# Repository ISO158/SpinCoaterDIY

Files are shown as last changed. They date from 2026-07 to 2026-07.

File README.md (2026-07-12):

# Spin Coater (DIY)

Este projeto consiste no desenvolvimento e validação de um **Spin Coater de baixo custo (DIY)** voltado para a instrumentação e preparação de amostras em biofísica de membranas. Utilizando peças impressas em 3D, componentes de drones e um microcontrolador ESP32, o equipamento foi projetado para produzir filmes lipídicos finos e homogêneos sobre lâminas de vidro com alta reprodutibilidade.

---

## 📺 Demonstração em Vídeo

Você pode conferir o funcionamento prático do Spin Coater através do vídeo abaixo:

Demonstração do Spin Coater (https://www.youtube.com/shorts/L5SzGOxu2F8)

> 🎥 *Clique na imagem acima para assistir ao funcionamento do Spin Coater no YouTube Shorts.*

---

## 🛠️ Especificações de Hardware e Eletrônica

O projeto integra hardware de modelagem própria e componentes robustos gerenciados pelo ESP32.

### 🔌 Diagrama Elétrico
Abaixo está o esquema de conexões da eletrônica, englobando a fonte chaveada, o conversor de tensão DC-DC, o microcontrolador e a telemetria do motor:
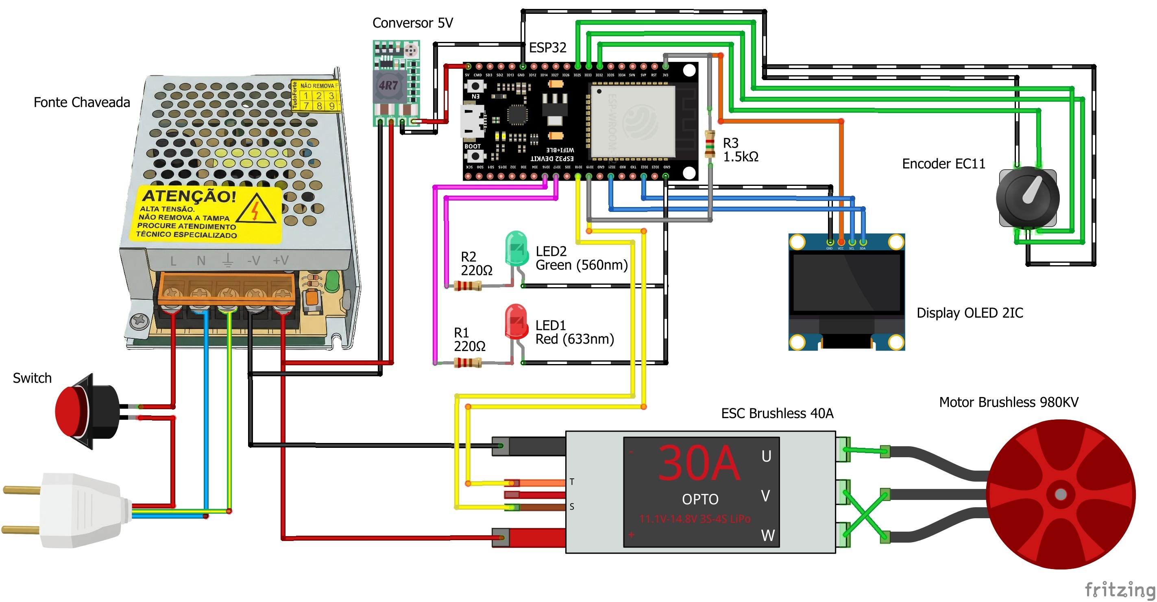
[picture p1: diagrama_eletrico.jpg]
Diagrama Elétrico


*   **Microcontrolador:** ESP32 DevKit v1
*   **Motorização:** Motor Brushless Outrunner 980KV (comum em drones) acoplado a um ESC Brushless de 40A com telemetria ativa.
*   **Interface Física:** Display OLED I2C (SSD1306 128x64) e um Encoder Rotativo EC11 com botão integrado para navegação nos menus.
*   **Sinalização:** LEDs indicadores (Verde/Vermelho) para status de operação segura.

### 📐 Estrutura Física e Modelagem 3D (OpenSCAD)
O gabinete externo e o arranjo dos componentes internos foram inteiramente modelados em OpenSCAD. A carcaça estrutural foi projetada com **5mm de espessura**, permitindo um preenchimento do tipo *Gyroid* (efeito sanduíche) para minimizar tensões térmicas e vibrações de alta rotação.
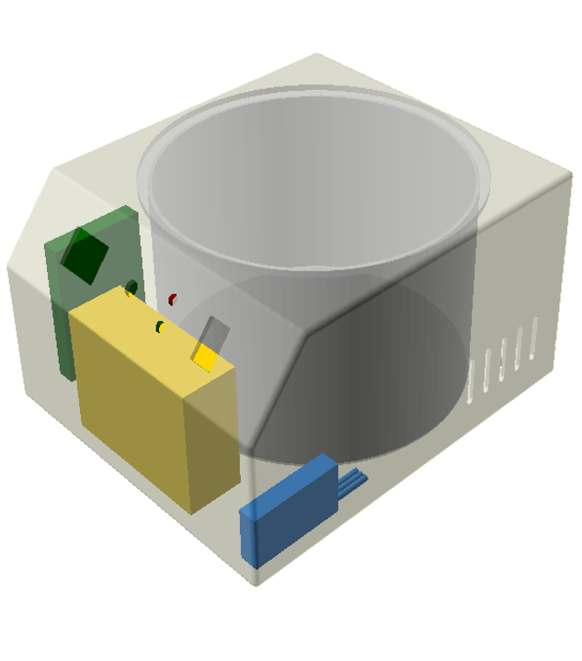
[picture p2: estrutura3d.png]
Estrutura 3D renderizada


A câmara de centrifugação utiliza uma **forma de alumínio de 16cm de diâmetro**, fixada à base por parafusos M6 e isolada por amortecimento de EVA para conter respingos e estabilizar mecanicamente o sistema. Os pés do gabinete possuem furação para parafusos M8.

Aqui está o equipamento montado e finalizado:
<p align="center">
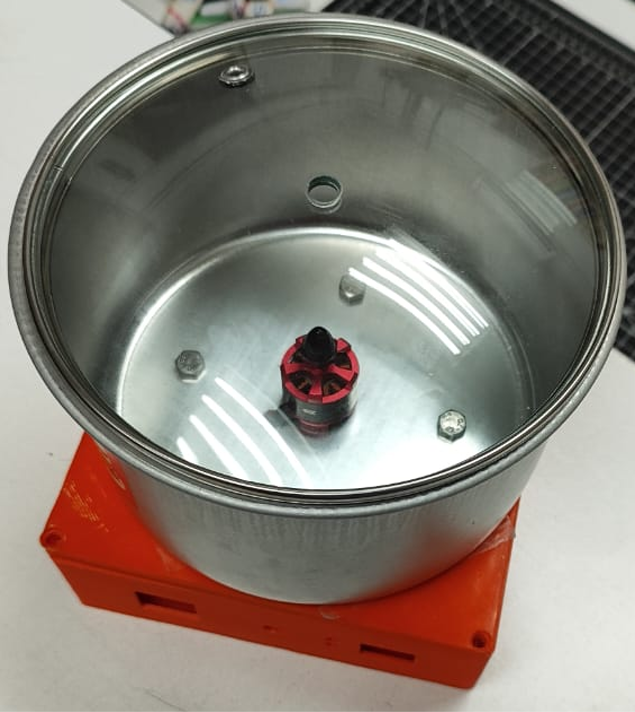
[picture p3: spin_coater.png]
Montagem Interna
  
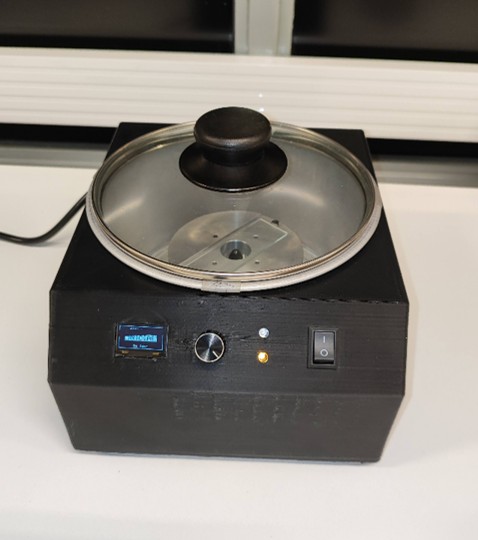
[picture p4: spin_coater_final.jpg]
Produto Finalizado
  
</p>

---

## 💻 Arquitetura do Firmware (ESP32)

O código desenvolvido em C++ implementa uma máquina de estados robusta (`TELA_HOME`, `TELA_CONFIG`, `MODO_DEPOSICAO`, `MODO_SPIN`, `MODO_FREIO`, etc.) e algoritmos críticos de automação industrial:

1.  **Vencimento de Inércia (*Kickstart*):** Ao iniciar, o motor recebe um pulso de PWM de $1150\,\mu\text{s}$ por $150\,\text{ms}$ para vencer o peso inicial do mandril de fixação (*chuck*).
2.  **Rampa de Aceleração Controlada:** Aceleração linear com duração fixa de $2000\,\text{ms}$ para evitar o descolamento abrupto da solução lipídica.
3.  **Compensador de Carga Ativo:** Em alta rotação (acima de $4650\text{ RPM}$), o firmware faz leituras contínuas da telemetria a cada $200\,\text{ms}$. Se a rotação real desviar mais de $100\text{ RPM}$ do alvo (`TOLERANCIA_CARGA`), o PWM é ajustado dinamicamente via software para compensar o arrasto aerodinâmico.
4.  **Frenagem Dinâmica Suave:** O motor desacelera em passos controlados de PWM para impedir danos ao eixo do motor ou deslocamento indesejado da amostra antes do corte total de inércia.

---

## 📊 Resultados e Validação

O sistema foi rigorosamente calibrado e testado para avaliar a estabilidade eletrônica, o comportamento mecânico e a qualidade biológica dos filmes obtidos.

### 📈 Calibração de Velocidade e Resíduos
A resposta de velocidade (RPM) em função do sinal PWM ($\mu\text{s}$) apresentou excelente comportamento linear em toda a faixa de operação do motor. A dispersão dos resíduos se mantém muito baixa, permitindo alta fidelidade na seleção da rotação.
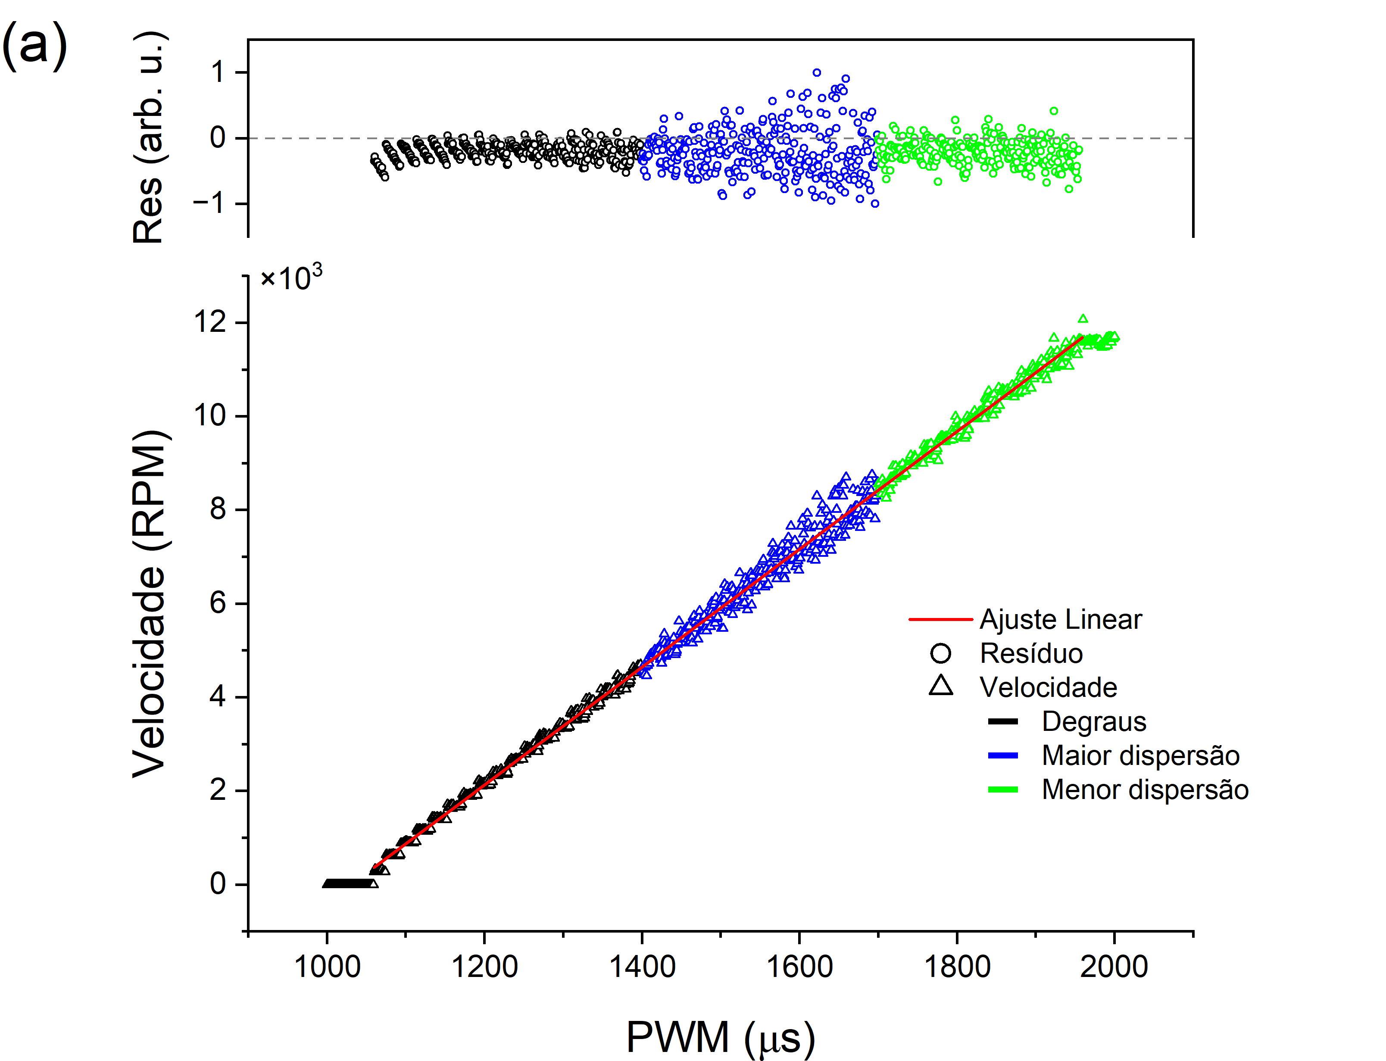
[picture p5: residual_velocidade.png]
Ajuste Linear de Velocidade


### 🌡️ Tensão e Temperatura
A telemetria monitorou a temperatura do ESC e a tensão da fonte durante os testes. A temperatura segue um ajuste quadrático esperado devido ao efeito Joule, estabilizando-se em níveis seguros abaixo de $44^\circ\text{C}$, enquanto a tensão da fonte chaveada permanece perfeitamente estável em torno de $12.6\text{ V}$.
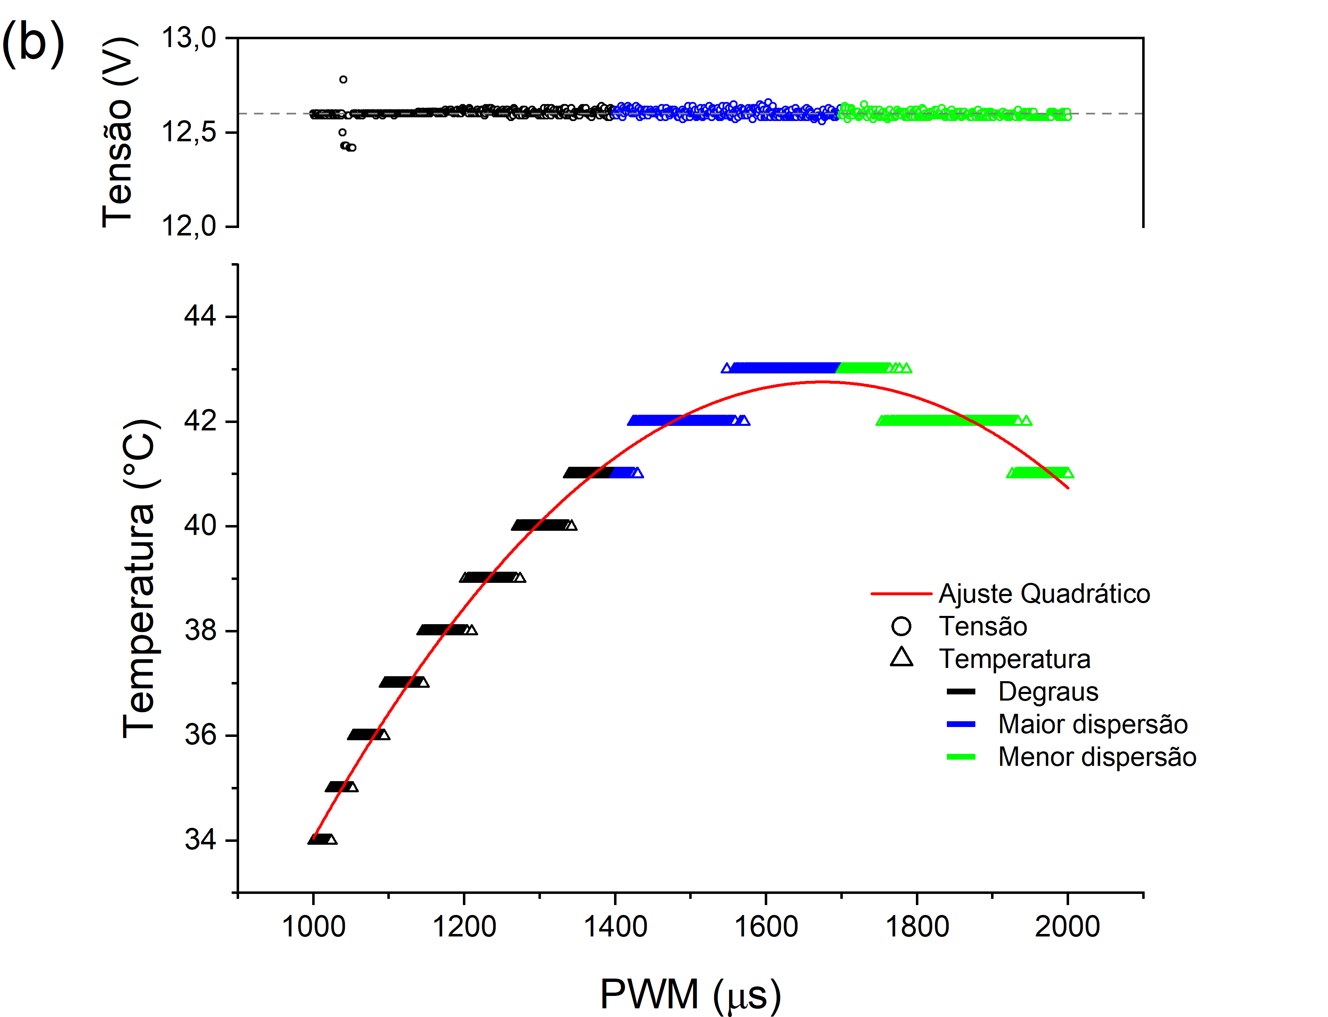
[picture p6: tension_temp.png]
Gráfico de Tensão e Temperatura


### 🔬 Homogeneidade das Amostras Lipídicas
O teste definitivo de bancada validou o propósito biológico do equipamento. Na imagem abaixo, é possível ver o contraste entre uma deposição manual (A) e o filme lipídico uniforme gerado pelo Spin Coater (B). Sob microscopia (C), a transição nítida evidencia a formação de um filme extremamente fino e homogêneo sobre a lâmina de vidro.
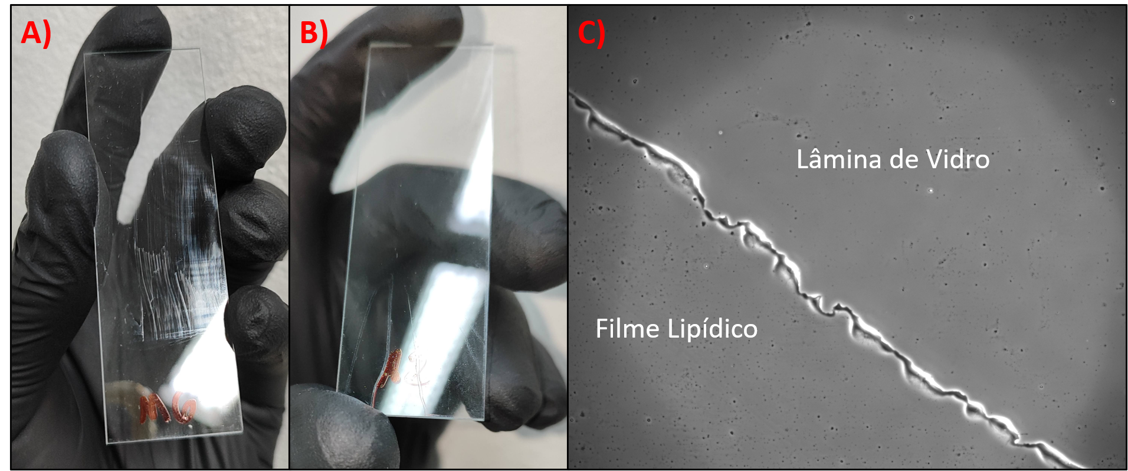
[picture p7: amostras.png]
Comparativo de Amostras


---

## 🛠️ Como Executar o Projeto

1.  **Modelagem 3D:** Os arquivos `.scad` podem ser modificados e exportados para `.STL` utilizando o [OpenSCAD](https://openscad.org/).
2.  **Firmware:** 
    *   Abra o código na Arduino IDE ou PlatformIO.
    *   Instale as bibliotecas necessárias: `Adafruit_GFX`, `Adafruit_SSD1306` e `ESP32Servo`.
    *   Compile e faça o upload para o ESP32 conectado às pinagens indicadas no cabeçalho do código.

---
*Desenvolvido por **Igor** como parte de soluções instrumentais aplicadas à pesquisa científica.*

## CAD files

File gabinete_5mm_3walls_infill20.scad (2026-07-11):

// ==========================================
// PROJETO SPIN COATER - VERSÃO FINAL (5mm ESTRUTURAL)
// ==========================================

// --- DIMENSÕES DO GABINETE (mm) ---
// Decisão Final: 5mm permite infill Gyroid funcional (efeito sanduíche)
// reduzindo a tensão térmica interna comparado a uma parede fina sólida.
espessura_base_topo = 5; 
espessura_laterais = 5;  

largura_total = 180;  
profundidade_total = 210; 
altura_total = 107;   

raio_arredondamento = 3; 

// --- GEOMETRIA DO TRAPÉZIO FRONTAL ---
altura_base_painel = 70;  
altura_topo_painel = 100; 
recuo_painel = 30; 

// --- POSIÇÃO DO BURACO DA FORMA ---
raio_forma = 80; // 16cm diâmetro
// Distância do fundo ajustada para parede de 5mm
y_centro_forma = profundidade_total - espessura_laterais - 5 - raio_forma;

// --- CÁLCULO DO ÂNGULO DO PAINEL ---
cateto_oposto = recuo_painel;
cateto_adjacente = altura_topo_painel - altura_base_painel;
angulo_painel = atan(cateto_oposto / cateto_adjacente); 

$fn = 100; 

module CorpoGabinete() {
    hull() {
        // --- PARTE TRASEIRA ---
        translate([raio_arredondamento, profundidade_total-raio_arredondamento, raio_arredondamento]) sphere(r=raio_arredondamento);
        translate([largura_total-raio_arredondamento, profundidade_total-raio_arredondamento, raio_arredondamento]) sphere(r=raio_arredondamento);
        translate([raio_arredondamento, profundidade_total-raio_arredondamento, altura_total-raio_arredondamento]) sphere(r=raio_arredondamento);
        translate([largura_total-raio_arredondamento, profundidade_total-raio_arredondamento, altura_total-raio_arredondamento]) sphere(r=raio_arredondamento);
        
        // --- PARTE FRONTAL ---
        translate([raio_arredondamento, raio_arredondamento, raio_arredondamento]) sphere(r=raio_arredondamento);
        translate([largura_total-raio_arredondamento, raio_arredondamento, raio_arredondamento]) sphere(r=raio_arredondamento);
        
        translate([raio_arredondamento, raio_arredondamento, altura_base_painel]) sphere(r=raio_arredondamento);
        translate([largura_total-raio_arredondamento, raio_arredondamento, altura_base_painel]) sphere(r=raio_arredondamento);
        
        translate([raio_arredondamento, recuo_painel + raio_arredondamento, altura_topo_painel]) sphere(r=raio_arredondamento);
        translate([largura_total-raio_arredondamento, recuo_painel + raio_arredondamento, altura_topo_painel]) sphere(r=raio_arredondamento);
        
        translate([raio_arredondamento, recuo_painel + raio_arredondamento, altura_total-raio_arredondamento]) sphere(r=raio_arredondamento);
        translate([largura_total-raio_arredondamento, recuo_painel + raio_arredondamento, altura_total-raio_arredondamento]) sphere(r=raio_arredondamento);
    }
}

module GabineteFinal() {
    difference() {
        // 1. Sólido Externo
        CorpoGabinete();
        
        // 2. Oco Interno (AGORA UNIFORME 8mm)
        altura_interna = altura_total - (2 * espessura_base_topo);

        difference() {
            hull() {
                // Fundo Traseiro
                translate([espessura_laterais, profundidade_total-espessura_laterais, espessura_base_topo]) 
                cylinder(r=1, h=altura_interna);
                translate([largura_total-espessura_laterais, profundidade_total-espessura_laterais, espessura_base_topo]) 
                cylinder(r=1, h=altura_interna);
                
                // Frente Baixo
                translate([espessura_laterais, espessura_laterais, espessura_base_topo]) 
                cylinder(r=1, h=altura_base_painel - espessura_base_topo);
                translate([largura_total-espessura_laterais, espessura_laterais, espessura_base_topo]) 
                cylinder(r=1, h=altura_base_painel - espessura_base_topo);
                
                // Frente Angulo
                translate([espessura_laterais, recuo_painel+3, altura_topo_painel - espessura_base_topo]) cylinder(r=1, h=1);
                translate([largura_total-espessura_laterais, recuo_painel+3, altura_topo_painel - espessura_base_topo]) cylinder(r=1, h=1);
                    
                // Frente Topo
                translate([espessura_laterais, recuo_painel+3, altura_total - espessura_base_topo]) cylinder(r=1, h=1);
                translate([largura_total-espessura_laterais, recuo_painel+3, altura_total - espessura_base_topo]) cylinder(r=1, h=1);
            }
             translate([0,0,-5]) cube([largura_total, profundidade_total, 1]); 
        }
        
        // --- FURO DA FORMA ---
        translate([largura_total/2, y_centro_forma, altura_total - 20]) cylinder(h = 30, r = raio_forma+4);
        // Fresta de 2mm no topo (rebaixo visual)
        translate([largura_total/2, y_centro_forma, altura_total-2]) cylinder(r=raio_forma+4, h=3);

        // --- COMPONENTES FRONTAIS ---
        z_centro_face = (altura_base_painel + altura_topo_painel) / 2;
        y_centro_face = recuo_painel / 2; 
        
        translate([0, y_centro_face + 5, z_centro_face]) 
        rotate([angulo_painel, 0, 0]) 
        {
            // Display
            translate([2*largura_total/5 -(25), 0, 0]) cube([26, 17, 50], center=true);
            // Rebaixo visual do display (mantido do original)
            rotate([3.5, 0, 0]) translate([2*largura_total/5 -(25), 0, 0]) cube([15, 26, 8], center=true);
            
            // Encoder
            translate([largura_total/2 -(7.2), 0, 0]) cylinder(h=50, r=3.6, center=true);
            // Rebaixo visual do Encoder (mantido do original)
            rotate([3.5, 0, 0]) translate([largura_total/2 -(7.2), 0, 0]) cube([15, 15, 8], center=true); 
            
            // LEDs
            translate([3*largura_total/5 -(0), +6,0]) cylinder(h=50, r=2.6, center=true); 
            translate([3*largura_total/5 -(0),-6,0]) cylinder(h=50, r=2.6, center=true); 
            
            // Interruptor
            translate([4*largura_total/5 -(6.5), 0,0]) cube([13, 19, 50], center=true);
            // Rebaixo visual do Interruptor (mantido do original)
            rotate([3.5, 0, 0]) translate([4*largura_total/5 -(6.5), 0, 0]) cube([16, 22, 8], center=true);
        }
        
        // --- SAÍDA CABO ---
        translate([largura_total-largura_total/4, profundidade_total+10, 15]) 
        rotate([90,0,0])
        hull() { 
            cylinder(h=20, r=4);
            translate([0, 0, 0]) cylinder(h=20, r=4);
        }
        
        // --- VENTILAÇÃO ---
        for(lado = [0, largura_total]) {
            translate([lado, 2*profundidade_total/3, 40]) 
            rotate([0, 90, 0])
            for(i=[0:4]) {
                translate([0, i*12, -10])
                hull() {
                    cylinder(r=2, h=20);
                    translate([20, 0, 0]) cylinder(r=2, h=20);
                }
            }
        }
        
        // --- PÉS M8 ---
        posicoes_pes = [
            [20, 20],
            [largura_total-20, 20],
            [20, profundidade_total-20],
            [largura_total-20, profundidade_total-20]
        ];
    
        for(pos = posicoes_pes) {
            translate([pos[0], pos[1], -10]) 
            cylinder(r=4, h=30); 
        }
        
        // --- FUROS FORMA M6 NA BASE ---
        distancia_furos_forma = 100; 
        diametro_furo_m6 = 6.2; 
        translate([largura_total/2, y_centro_forma, 0]) {
            translate([distancia_furos_forma / 2, 0, 0]) cylinder(h=20, d=diametro_furo_m6, center=true);
            translate([distancia_furos_forma / 2, 0, 0]) cylinder(h=5, d=diametro_furo_m6+5, center=true);
            
            translate([-distancia_furos_forma / 2, 0, 0]) cylinder(h=20, d=diametro_furo_m6, center=true);
            translate([-distancia_furos_forma / 2, 0, 0]) cylinder(h=5, d=diametro_furo_m6+5, center=true);
            
            translate([0, distancia_furos_forma / 2, 0]) cylinder(h=20, d=diametro_furo_m6, center=true);
            translate([0, distancia_furos_forma / 2, 0]) cylinder(h=5, d=diametro_furo_m6+5, center=true);
            
            translate([0, -distancia_furos_forma / 2, 0]) cylinder(h=20, d=diametro_furo_m6, center=true);
            translate([0, -distancia_furos_forma / 2, 0]) cylinder(h=5, d=diametro_furo_m6+5, center=true);
        }
        
    }
}

// ==========================================
// --- MÓDULOS DE VISUALIZAÇÃO ---
// ==========================================

module FormaAluminio() {
    color("Silver", 0.8) {
        difference() {
            cylinder(r=raio_forma, h=97); 
            translate([0,0,2]) cylinder(r=raio_forma-2, h=95); 
        }
        translate([0,0,97]) difference() {
            cylinder(r=raio_forma+5, h=3);
        }
    }
}

module EVA_Amortecimento() {
    color("Black", 0.2) {
        cylinder(r=raio_forma-1, h=2); 
    }
}

module FonteChaveada() {
    color("Gold") cube([85, 30, 60]); 
}

module ESP32() {
    color("DarkGreen") cube([50, 10, 70]); 
}
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

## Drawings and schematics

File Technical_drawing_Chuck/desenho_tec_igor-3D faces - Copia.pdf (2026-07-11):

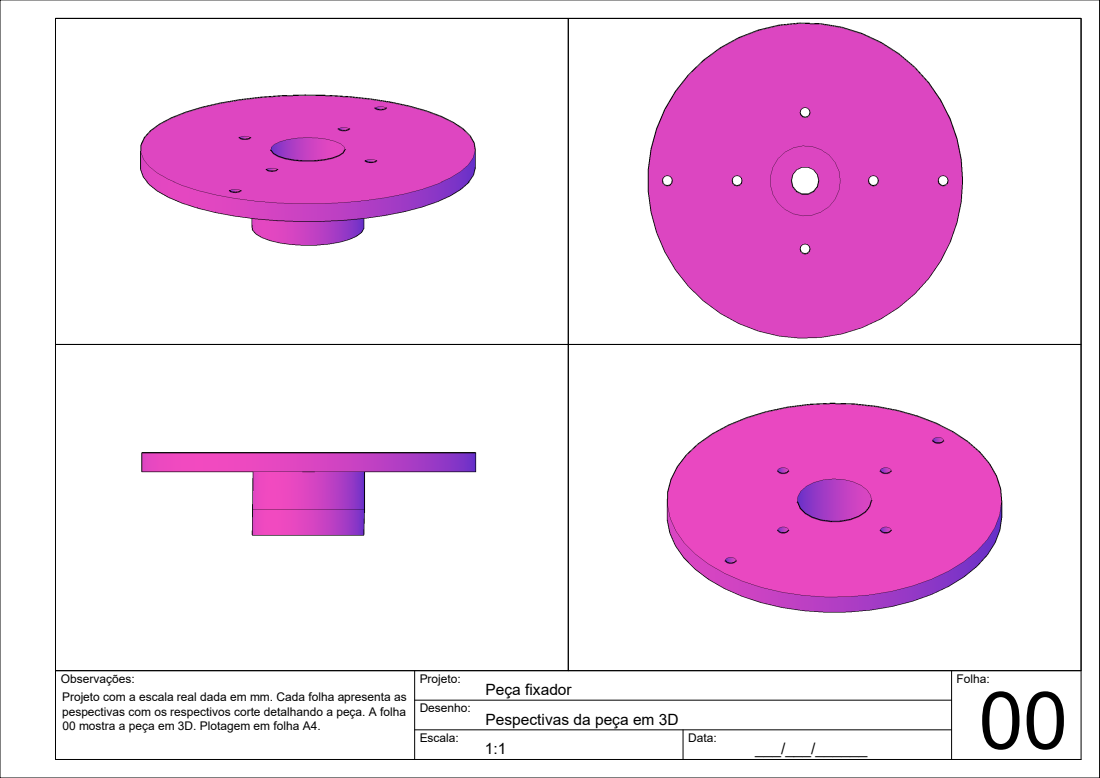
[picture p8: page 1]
Observações:; Peça fixador Projeto com a escala real dada em mm. Cada folha apresenta as

00 Pespectivas da peça em 3D

pespectivas com os respectivos corte detalhando a peça. A folha
00 mostra a peça em 3D. Plotagem em folha A4.

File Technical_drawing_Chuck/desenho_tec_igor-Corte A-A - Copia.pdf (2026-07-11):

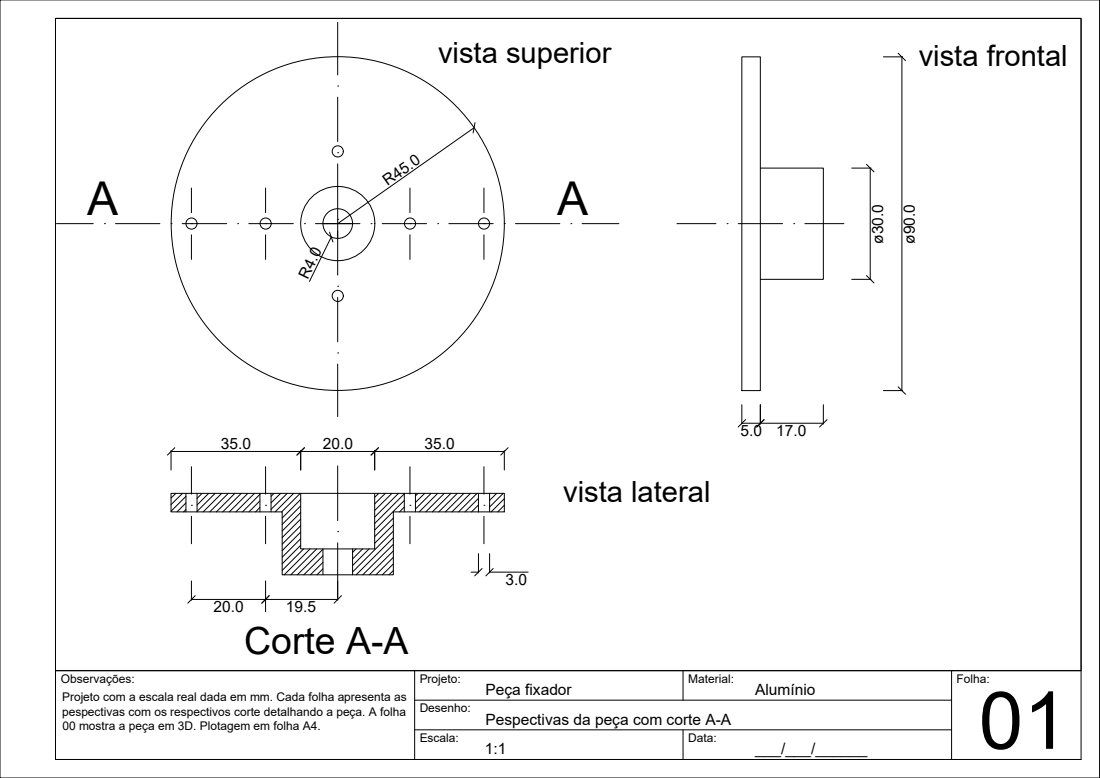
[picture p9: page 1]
vista superior; vista frontal; Corte A-A; vista lateral; Observações:; Peça fixador Projeto com a escala real dada em mm. Cada folha apresenta as

01 Pespectivas da peça com corte A-A

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

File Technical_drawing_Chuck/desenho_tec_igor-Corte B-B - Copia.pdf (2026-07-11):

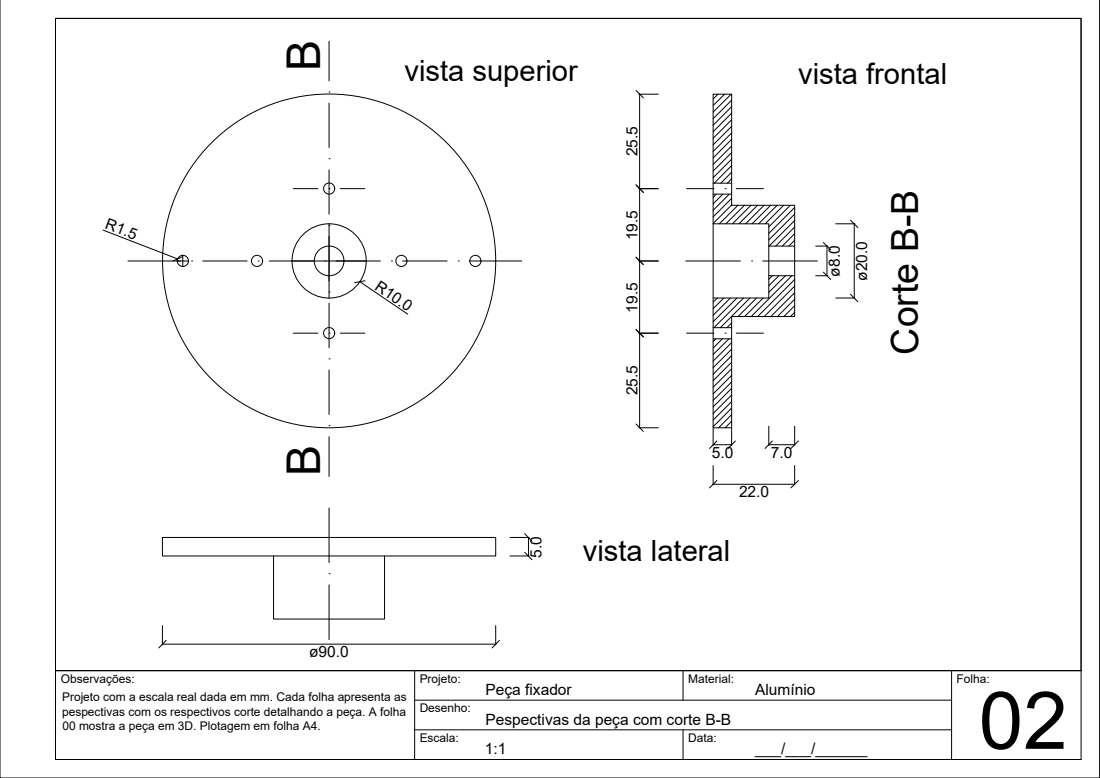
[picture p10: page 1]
vista superior; B Corte B-B; vista frontal; vista lateral; Observações:; Peça fixador Projeto com a escala real dada em mm. Cada folha apresenta as

02 Pespectivas da peça com corte B-B

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

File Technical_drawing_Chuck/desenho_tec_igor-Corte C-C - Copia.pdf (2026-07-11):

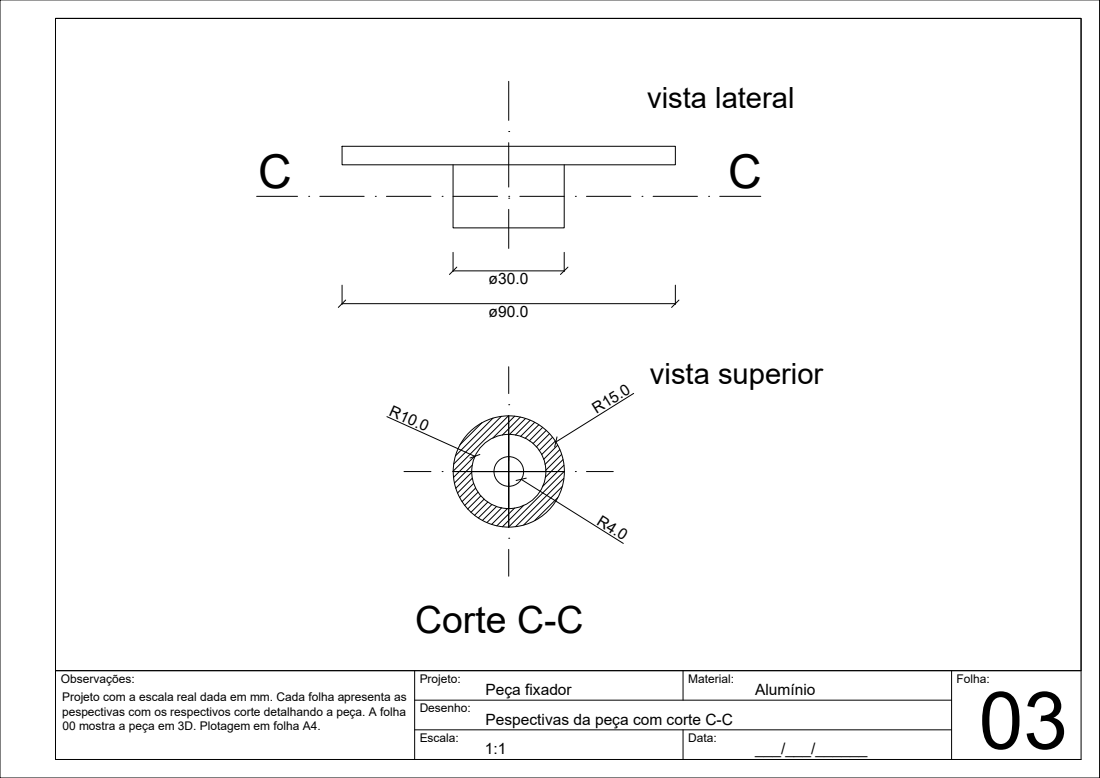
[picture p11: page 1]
vista lateral; vista superior; Corte C-C; Observações:; Peça fixador Projeto com a escala real dada em mm. Cada folha apresenta as

03 Pespectivas da peça com corte C-C

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

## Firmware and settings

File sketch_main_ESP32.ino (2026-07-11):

#include <Wire.h>
#include <Adafruit_GFX.h>
#include <Adafruit_SSD1306.h>
#include <ESP32Servo.h>

// ==========================================
// --- DEFINIÇÕES DE HARDWARE ---
// ==========================================

// --- PINAGEM DO MOTOR ---
const int escPin = 18;
const int pinTelemetria = 19;
const int PARES_DE_POLOS = 7;

// --- PINAGEM DOS LEDS ---
#define PIN_LED_VERMELHO 16 
#define PIN_LED_VERDE    17 

// --- PINAGEM DO ENCODER ---
#define ENC_CLK 25  
#define ENC_DT  33  
#define ENC_SW  32  

// ==========================================
// --- CONFIGURAÇÕES GERAIS ---
// ==========================================
#define INTERVALO_DISPLAY 500  
#define NUM_AMOSTRAS 50        
#define PWM_MIN 1055           
#define PWM_MAX 2000

#define PASSO_FREIO 4          
#define TEMPO_FREIO 20         

// ZONA DE CORTE (Hard Cut para não travar no fim)
#define PWM_CORTE_INERCIA 1130 

// Rampa de Aceleração (Tempo total em ms)
#define DURACAO_RAMPA 2000 

// --- PLATÔS SEGUROS (BAIXA ROTAÇÃO) ---
const int degrausSeguros[] = {
  570, 880, 1150, 1400, 1650, 1900, 2150, 2400, 2650, 
  2900, 3150, 3400, 3650, 3900, 4150, 4400, 4650 
};
const int numDegraus = sizeof(degrausSeguros) / sizeof(degrausSeguros[0]);

// A partir daqui, ativamos a CORREÇÃO DE CARGA
const int LIMITE_LINEAR = 4650; 

// ==========================================
// --- VARIÁVEIS GLOBAIS ---
// ==========================================
Servo esc;
Adafruit_SSD1306 display(128, 64, &Wire, -1);

int cfgDepositRPM = 570; 
int cfgMainRPM = 2150;    
int cfgTime = 30;         

long rpmMedio = 0;        
float voltagem = 0.0;     
float temperatura = 0.0;      

long amostrasRPM[NUM_AMOSTRAS]; 
int indiceAmostra = 0;
long somaAmostras = 0;

// Controle Motor
float pwmAtualFloat = 1000.0; 
int pwmAlvo = 1000;       
int pwmInicialRampa = 1000;
unsigned long inicioRampa = 0;
bool rampaAtiva = false;

// Compensador de Carga
unsigned long ultimoAjusteCarga = 0;
#define INTERVALO_COMPENSACAO 200 // Verifica a cada 200ms
#define TOLERANCIA_CARGA 100      // Só corrige se cair mais que 100 RPM

unsigned long tempoInicioSpin = 0;
unsigned long ultimaAtualizacaoDisplay = 0; 
unsigned long ultimoPassoFreio = 0; 

enum Estado { TELA_HOME, TELA_CONFIG, TELA_PRE_RUN, MODO_DEPOSICAO, MODO_SPIN, MODO_FREIO, TELA_FIM };
Estado estadoAtual = TELA_HOME;

int cursorLinha = 0;
int cursorPreRun = 0; 
bool botaoPressionado = false;
unsigned long ultimoClick = 0;

volatile int encoderCount = 0;
int lastEncoderCount = 0;

int indexDeposit = 0; 
int indexMain = 6;    

// ==========================================
// --- FUNÇÕES AUXILIARES ---
// ==========================================

// --- ENCODER E CRC ---
void IRAM_ATTR isrEncoder() {
  static unsigned long lastInterruptTime = 0;
  unsigned long interruptTime = millis();
  if (interruptTime - lastInterruptTime > 5) { 
    if (digitalRead(ENC_CLK) == digitalRead(ENC_DT)) {
      encoderCount--;
    } else {
      encoderCount++;
    }
    lastInterruptTime = interruptTime;
  }
}

uint8_t updateCrc8(uint8_t crc, uint8_t crc_seed) {
  uint8_t crc_u = crc ^ crc_seed;
  for (int i = 0; i < 8; i++) crc_u = (crc_u & 0x80) ? 0x7 ^ (crc_u << 1) : (crc_u << 1);
  return crc_u;
}

// --- CALIBRAÇÃO LINEAR ---
int rpmToPwmEstimado(int rpm) {
  if (rpm < 100) return 1000;
  float pwm = (0.0795 * rpm) + 1031;
  if (pwm < PWM_MIN) pwm = PWM_MIN;
  if (pwm > PWM_MAX) pwm = PWM_MAX;
  return (int)pwm;
}

// --- VISUAL ---
void desenharOpcaoInvertida(String texto, int y, bool selecionado) {
  int x = (128 - (texto.length() * 6)) / 2;
  if (selecionado) {
    display.fillRect(x - 2, y - 1, (texto.length() * 6) + 4, 10, WHITE);
    display.setTextColor(BLACK, WHITE);
  } else {
    display.setTextColor(WHITE);
  }
  display.setCursor(x, y); display.print(texto); display.setTextColor(WHITE);
}

void desenharBotaoGrande(String texto, int y, bool selecionado) {
  int larguraPx = texto.length() * 12;
  int x = (128 - larguraPx) / 2;
  display.setTextSize(2);
  if (selecionado) {
    display.fillRect(x - 4, y - 2, larguraPx + 8, 18, WHITE);
    display.setTextColor(BLACK, WHITE);
  } else {
    display.setTextColor(WHITE);
  }
  display.setCursor(x, y); display.print(texto); display.setTextColor(WHITE); display.setTextSize(1);
}

void desenharLinhaConfig(String label, String valor, String unidade, int y, bool selecionado) {
  if (selecionado) {
    display.fillRect(2, y - 1, 124, 10, WHITE);
    display.setTextColor(BLACK, WHITE);
  } else {
    display.setTextColor(WHITE);
  }
  display.setCursor(4, y); display.print(label);
  display.setCursor(65, y); display.print(valor); display.print(" "); display.print(unidade);
  display.setTextColor(WHITE);
}

void desenharDashboard(long rpmReal, int tempoTotal, int tempoRestante, int modo) {
  display.setTextSize(1);
  display.setCursor(4, 4); display.print(voltagem, 1); display.print(" V");
  display.setCursor(90, 4); display.print(temperatura, 1); display.print(" C");

  display.setTextSize(2);
  String sRpm = String(rpmReal);
  int xRpm = (128 - (sRpm.length() * 12)) / 2;
  xRpm -= 10; 
  display.setCursor(xRpm, 22); display.print(sRpm);
  display.setTextSize(1);
  display.setCursor(xRpm + (sRpm.length() * 12) + 2, 29); display.print("RPM");

  if (modo == 1 && tempoTotal > 0) { 
     display.drawRect(14, 45, 100, 6, WHITE);
     int tempoCorrido = tempoTotal - tempoRestante;
     int larguraBarra = map(tempoCorrido, 0, tempoTotal, 0, 96);
     if (larguraBarra > 96) larguraBarra = 96;
     display.fillRect(16, 47, larguraBarra, 2, WHITE);
     String sTempo = String(tempoRestante) + " s";
     int xTempo = (128 - (sTempo.length()*6))/2;
     display.setCursor(xTempo, 54); display.print(sTempo);
  }
  else if (modo == 2) { 
      display.setTextSize(1);
      desenharOpcaoInvertida("PARANDO...", 48, true);
  }
}

// ==========================================
// --- SETUP ---
// ==========================================
void setup() {
  Serial.begin(115200);

  // 1. INICIALIZAÇÃO IMEDIATA DO MOTOR (Evita bipes de erro)
  esc.setPeriodHertz(50);
  esc.attach(escPin, 1000, 2000);
  esc.writeMicroseconds(1000); // Crava o pino em 1000us na largada
  
  // O resto da placa continua inicializando enquanto o ESC lê o sinal zero
  pinMode(PIN_LED_VERMELHO, OUTPUT);
  pinMode(PIN_LED_VERDE, OUTPUT);
  
  digitalWrite(PIN_LED_VERMELHO, HIGH); delay(200); digitalWrite(PIN_LED_VERMELHO, LOW);
  digitalWrite(PIN_LED_VERDE, HIGH); delay(200); digitalWrite(PIN_LED_VERDE, LOW);

  for(int i=0; i<NUM_AMOSTRAS; i++) amostrasRPM[i] = 0;

  pinMode(ENC_CLK, INPUT_PULLUP);
  pinMode(ENC_DT, INPUT_PULLUP);
  pinMode(ENC_SW, INPUT_PULLUP);
  attachInterrupt(digitalPinToInterrupt(ENC_CLK), isrEncoder, RISING);

  // 2. INICIALIZA O DISPLAY
  if(!display.begin(SSD1306_SWITCHCAPVCC, 0x3C)) { for(;;); }
  display.setTextColor(WHITE);
  
  display.clearDisplay();
  display.setTextSize(1);
  display.setCursor(10,30); display.println("Booting System...");
  display.display();
  
  // 3. DELAY DE ARME DO ESC (A tela fica estática por 2s enquanto o motor bipa)
  delay(2000); 

  // 4. INICIALIZA A TELEMETRIA
  Serial2.begin(115200, SERIAL_8N1, pinTelemetria, -1);
}

void gerenciarLeds() {
  if (estadoAtual == MODO_DEPOSICAO || estadoAtual == MODO_SPIN || estadoAtual == MODO_FREIO) {
    digitalWrite(PIN_LED_VERMELHO, HIGH); 
    digitalWrite(PIN_LED_VERDE, LOW);
  } else {
    digitalWrite(PIN_LED_VERMELHO, LOW);
    digitalWrite(PIN_LED_VERDE, HIGH);    
  }
}

// ==========================================
// --- LÓGICA DE CONTROLE (RAMPA E CARGA) ---
// ==========================================
void iniciarNovaRampa(int novoAlvo) {
  pwmAlvo = novoAlvo;

  // --- KICKSTART PARA VENCER A INÉRCIA DO CHUCK ---
  // Se o motor estava desligado e mandamos ligar, dá um tranco de 150ms
  if (pwmAtualFloat < 1050 && novoAlvo > 1000) {
    esc.writeMicroseconds(1150); // PWM mais forte para o motor dar um "pulo"
    delay(150);                  // Tempo suficiente só para vencer a inércia
  }
  // ------------------------------------------------------

  // Jump Start para baixas velocidades (ignora rampa)
  if (pwmAlvo <= PWM_CORTE_INERCIA) {
    pwmAtualFloat = pwmAlvo;
    rampaAtiva = false; 
    esc.writeMicroseconds(pwmAlvo);
    return;
  }

  pwmInicialRampa = (int)pwmAtualFloat; 
  if (pwmInicialRampa < 1000) pwmInicialRampa = 1000;
  inicioRampa = millis();
  rampaAtiva = true;
}

void atualizarRampa() {
  if (!rampaAtiva) return;

  unsigned long tempoDecorrido = millis() - inicioRampa;

  if (tempoDecorrido >= DURACAO_RAMPA) {
    pwmAtualFloat = pwmAlvo;
    rampaAtiva = false;
  } 
  else {
    float progresso = (float)tempoDecorrido / (float)DURACAO_RAMPA;
    pwmAtualFloat = pwmInicialRampa + ((pwmAlvo - pwmInicialRampa) * progresso);
  }
  esc.writeMicroseconds((int)pwmAtualFloat);
}

// --- COMPENSADOR DE CARGA (Só p/ Alta Rotação) ---
void compensarCarga() {
  if (!rampaAtiva && pwmAlvo > rpmToPwmEstimado(LIMITE_LINEAR)) {
    if (millis() - ultimoAjusteCarga > INTERVALO_COMPENSACAO) {
      
      long erro = cfgMainRPM - rpmMedio;

      if (erro > TOLERANCIA_CARGA) {
         pwmAtualFloat += 1.0; 
         if (pwmAtualFloat > PWM_MAX) pwmAtualFloat = PWM_MAX;
         esc.writeMicroseconds((int)pwmAtualFloat);
      }
      else if (erro < -TOLERANCIA_CARGA) {
         pwmAtualFloat -= 1.0;
         if (pwmAtualFloat < PWM_MIN) pwmAtualFloat = PWM_MIN;
         esc.writeMicroseconds((int)pwmAtualFloat);
      }
      ultimoAjusteCarga = millis();
    }
  }
}

// ==========================================
// --- LOOP PRINCIPAL ---
// ==========================================
void loop() {
  processarTelemetria();
  gerenciarLeds();

  if (digitalRead(ENC_SW) == LOW) {
    if (millis() - ultimoClick > 300) {
      botaoPressionado = true;
      ultimoClick = millis();
    }
  }

  switch (estadoAtual) {
    case TELA_HOME:      loopHome();      break;
    case TELA_CONFIG:    loopConfig();    break;
    case TELA_PRE_RUN:   loopPreRun();    break;
    case MODO_DEPOSICAO: loopDeposicao(); break;
    case MODO_SPIN:      loopSpin();      break;
    case MODO_FREIO:     loopFreio();     break;
    case TELA_FIM:       loopFim();       break;
  }
}

void processarTelemetria() {
  while (Serial2.available() >= 10) {
    uint8_t buf[10];
    if (Serial2.peek() > 150) { Serial2.read(); continue; }
    Serial2.readBytes(buf, 10);
    uint8_t crc = 0;
    for (int i = 0; i < 9; i++) crc = updateCrc8(crc, buf[i]);
    if (crc == buf[9]) {
      uint16_t rpmWord = (buf[7] << 8) | buf[8];
      long leituraInstantanea = (long(rpmWord) * 100) / PARES_DE_POLOS;
      somaAmostras -= amostrasRPM[indiceAmostra]; 
      amostrasRPM[indiceAmostra] = leituraInstantanea; 
      somaAmostras += leituraInstantanea; 
      indiceAmostra++;
      if (indiceAmostra >= NUM_AMOSTRAS) indiceAmostra = 0; 
      rpmMedio = somaAmostras / NUM_AMOSTRAS;
      temperatura = buf[0];
      uint16_t voltageWord = (buf[1] << 8) | buf[2];
      voltagem = (float)voltageWord / 100.0;
    }
  }
}

bool horaDeAtualizarTela() {
  if (millis() - ultimaAtualizacaoDisplay > INTERVALO_DISPLAY) {
    ultimaAtualizacaoDisplay = millis();
    return true;
  }
  return false;
}

// ==========================================
// --- MÁQUINAS DE ESTADO ---
// ==========================================

void loopHome() {
  esc.writeMicroseconds(1000);
  pwmAtualFloat = 1000;
  rampaAtiva = false;
  if (botaoPressionado) {
    botaoPressionado = false;
    cursorLinha = 0; 
    cursorPreRun = 0;
    estadoAtual = TELA_CONFIG;
    display.clearDisplay(); 
    return;
  }
  if (horaDeAtualizarTela()) {
      display.clearDisplay();
      display.drawRect(0, 0, 128, 64, WHITE);
      display.setTextSize(1);
      display.setCursor(31,6); display.println("SPIN COATER");
      desenharBotaoGrande("INICIAR", 25, true); 
      display.setTextSize(1);
      display.setCursor(43, 52); display.println("by Igor");
      display.display();
  }
}

void loopConfig() {
  bool mudouAlgo = false;
  if (encoderCount != lastEncoderCount) {
    int delta = encoderCount - lastEncoderCount;
    mudouAlgo = true;
    
    if (cursorLinha == 0) { 
       if (cfgDepositRPM < LIMITE_LINEAR) {
          if (delta > 0) indexDeposit++; else indexDeposit--;
          if (indexDeposit < 0) indexDeposit = 0;
          if (indexDeposit >= numDegraus) indexDeposit = numDegraus - 1;
          cfgDepositRPM = degrausSeguros[indexDeposit];
       } else {
          cfgDepositRPM += delta * 100;
          if (cfgDepositRPM < LIMITE_LINEAR) {
             indexDeposit = numDegraus - 2; 
             cfgDepositRPM = degrausSeguros[indexDeposit];
          }
       }
       if (cfgDepositRPM > cfgMainRPM) cfgMainRPM = cfgDepositRPM;
    }
    else if (cursorLinha == 1) { 
       if (cfgMainRPM < LIMITE_LINEAR) {
          if (delta > 0) indexMain++; else indexMain--;
          if (indexMain < 0) indexMain = 0;
          if (indexMain >= numDegraus) indexMain = numDegraus - 1;
          cfgMainRPM = degrausSeguros[indexMain];
       } else {
          cfgMainRPM += delta * 100;
          if (cfgMainRPM < LIMITE_LINEAR) {
             indexMain = numDegraus - 2;
             cfgMainRPM = degrausSeguros[indexMain];
          }
       }
       if (cfgMainRPM < cfgDepositRPM) cfgMainRPM = cfgDepositRPM;
       if (cfgMainRPM > 12000) cfgMainRPM = 12000;
    }
    else if (cursorLinha == 2) { 
       cfgTime += delta;
       if (cfgTime < 1) cfgTime = 1;
       if (cfgTime > 600) cfgTime = 600;
    }
    lastEncoderCount = encoderCount;
  }

  if (botaoPressionado) {
    botaoPressionado = false;
    mudouAlgo = true;
    cursorLinha++;
    if (cursorLinha > 2) { 
       cursorLinha = 0;
       estadoAtual = TELA_PRE_RUN;
       display.clearDisplay(); 
       return;
    }
  }

  if (mudouAlgo || horaDeAtualizarTela()) {
      display.clearDisplay();
      display.drawRect(0, 0, 128, 64, WHITE);
      desenharLinhaConfig("Deposit", String(cfgDepositRPM), "RPM", 10, (cursorLinha==0));
      desenharLinhaConfig("Speed",   String(cfgMainRPM),    "RPM", 26, (cursorLinha==1));
      desenharLinhaConfig("Time",    String(cfgTime),       "s",   42, (cursorLinha==2));
      display.display();
  }
}

void loopPreRun() {
  bool mudou = false;
  if (encoderCount != lastEncoderCount) {
     int delta = encoderCount - lastEncoderCount;
     if (delta > 0) cursorPreRun++; else cursorPreRun--;            
     if (cursorPreRun < 0) cursorPreRun = 0; 
     if (cursorPreRun > 2) cursorPreRun = 2; 
     lastEncoderCount = encoderCount;
     mudou = true;
  }
  if (botaoPressionado) {
    botaoPressionado = false;
    if (cursorPreRun == 0) estadoAtual = MODO_DEPOSICAO;
    else if (cursorPreRun == 1) estadoAtual = TELA_CONFIG;
    else if (cursorPreRun == 2) estadoAtual = TELA_HOME;
    display.clearDisplay();
    return;
  }
  if (mudou || horaDeAtualizarTela()) {
      display.clearDisplay();
      display.drawRect(0, 0, 128, 64, WHITE);
      display.setTextSize(1);
      desenharOpcaoInvertida("INICIAR", 15, (cursorPreRun == 0));
      desenharOpcaoInvertida("EDITAR",  30, (cursorPreRun == 1));
      desenharOpcaoInvertida("SAIR",    45, (cursorPreRun == 2));
      display.display();
  }
}

void loopDeposicao() {
  if (!rampaAtiva && pwmAlvo != rpmToPwmEstimado(cfgDepositRPM)) {
     iniciarNovaRampa(rpmToPwmEstimado(cfgDepositRPM));
  }
  
  atualizarRampa();
  
  if (cfgDepositRPM > LIMITE_LINEAR) compensarCarga();

  if (botaoPressionado) {
    botaoPressionado = false;
    tempoInicioSpin = millis();
    iniciarNovaRampa(rpmToPwmEstimado(cfgMainRPM)); 
    estadoAtual = MODO_SPIN;
    display.clearDisplay();
    return;
  }
  if (horaDeAtualizarTela()) {
      display.clearDisplay();
      display.drawRect(0, 0, 128, 64, WHITE);
      desenharDashboard(rpmMedio, 0, 0, 0);
      desenharOpcaoInvertida("ACELERAR", 52, true);
      display.display();
  }
}

void loopSpin() {
  unsigned long tempoCorrido = (millis() - tempoInicioSpin) / 1000;
  long tempoRestante = cfgTime - tempoCorrido;

  if (tempoRestante <= 0) {
    estadoAtual = MODO_FREIO;
    display.clearDisplay();
    return;
  }

  atualizarRampa();
  
  if (cfgMainRPM > LIMITE_LINEAR) compensarCarga();

  if (botaoPressionado) {
    botaoPressionado = false;
    estadoAtual = MODO_FREIO;
    display.clearDisplay();
    return;
  }
  if (horaDeAtualizarTela()) {
      display.clearDisplay();
      display.drawRect(0, 0, 128, 64, WHITE);
      desenharDashboard(rpmMedio, cfgTime, tempoRestante, 1);
      display.display();
  }
}

void loopFreio() {
  if (millis() - ultimoPassoFreio > TEMPO_FREIO) {
    pwmAtualFloat -= PASSO_FREIO; 
    
    // HARD CUT: Zona de instabilidade
    if (pwmAtualFloat < PWM_CORTE_INERCIA) {
      pwmAtualFloat = 1000;
      esc.writeMicroseconds(1000);
      delay(200); 
      estadoAtual = TELA_FIM; 
      return;
    }
    esc.writeMicroseconds((int)pwmAtualFloat);
    ultimoPassoFreio = millis();
  }
  if (horaDeAtualizarTela()) {
      display.clearDisplay();
      display.drawRect(0, 0, 128, 64, WHITE);
      desenharDashboard(rpmMedio, 0, 0, 2);
      display.display();
  }
}

void loopFim() {
  esc.writeMicroseconds(1000); 
  pwmAtualFloat = 1000;
  rampaAtiva = false;
  if (botaoPressionado) {
    botaoPressionado = false;
    estadoAtual = TELA_HOME;
    display.clearDisplay();
    return;
  }
  if (horaDeAtualizarTela()) {
      display.clearDisplay();
      display.drawRect(0, 0, 128, 64, WHITE);
      display.setTextSize(2);
      display.setCursor(10,20); display.println("CONCLUIDO");
      display.setTextSize(1);
      desenharOpcaoInvertida("REINICIAR", 45, true);
      display.display();
  }
}
